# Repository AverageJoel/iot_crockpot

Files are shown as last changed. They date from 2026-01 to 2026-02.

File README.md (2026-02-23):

# IoT Crockpot Controller

An open-source, internet-enabled crockpot controller with a local touchscreen UI and remote Telegram control. Built on a custom single-board design around the ESP32-S3-WROOM-1-N4R2 and a 3.5" IPS capacitive touch display.

## Features

- **Remote Control via Telegram** — Control and monitor from anywhere; automatic safety alerts sent to Telegram on shutoff events
- **3.5" IPS Capacitive Touchscreen** — Full-color LVGL UI with OFF/WARM/LOW/HIGH controls, temperature arc, and multi-screen navigation
- **K-Type Thermocouple** — Accurate temperature monitoring via MAX31855
- **Safety System** — Auto-shutoff at 300°F, persistent sensor-error shutoff, task watchdog timer, relay fails to OFF on any fault
- **NVS Configuration** — WiFi credentials and Telegram token stored in non-volatile flash; configurable via `idf.py menuconfig`

## Architecture

Single custom PCB — ESP32-S3 handles everything directly:

```
                    ┌───────────────────────────────────────┐
                    │        ESP32-S3-WROOM-1-N4R2          │
                    │                                       │
   USB-C ──────────►│ GPIO19/20 (USB Serial/JTAG)           │
                    │                                       │
   3.5" Display ───►│ SPI2: SCK/MOSI/MISO + LCD_CS/DC/RST  │
   FT6336U Touch ──►│ I2C:  SDA/SCL + CTP_RST/INT          │
   Backlight PWM ───►│ GPIO47 (LCD_BL)                      │
                    │                                       │
   MAX31855 TC ─────►│ SPI2: MISO/SCK + TC_CS (GPIO16)      │
   Relay/SSR ───────►│ GPIO17                               │
                    │                                       │
                    │  WiFi 802.11n ──────────────► Internet│
                    └───────────────────────────────────────┘

Power: AC Mains → HLK-5M05 (5V) → AP2112K (3.3V) → ESP32 + Display + TC
```

See [docs/hardware_decisions.md](docs/hardware_decisions.md) for the full design rationale and component selection.

## Project Structure

```
iot_crockpot/
├── firmware/
│   ├── main/
│   │   ├── main.c              # Entry point, boot log, task creation
│   │   ├── crockpot.c/.h       # Core state machine (OFF/WARM/LOW/HIGH)
│   │   ├── temperature.c/.h    # MAX31855 SPI driver, thermocouple reading
│   │   ├── relay.c/.h          # GPIO relay/SSR control
│   │   ├── wifi.c/.h           # WiFi connection management
│   │   ├── telegram.c/.h       # Telegram bot (long-poll, commands, alerts)
│   │   ├── nvs_config.c/.h     # NVS read/write helpers
│   │   ├── display.c/.h        # LVGL init, lvgl_port setup
│   │   ├── display_driver.c/.h # ST7796 SPI driver (esp_lcd)
│   │   ├── touch_driver.c/.h   # FT6336U I2C driver (esp_lcd_touch)
│   │   ├── spi_bus.c/.h        # Shared SPI2 bus init
│   │   ├── gui.c/.h            # LVGL screens and widgets
│   │   ├── Kconfig.projbuild   # GPIO and WiFi/Telegram config options
│   │   └── idf_component.yml   # LVGL + esp_lcd component dependencies
│   ├── CMakeLists.txt
│   └── sdkconfig.defaults      # Default config (fonts, watchdog, etc.)
├── hardware/                   # KiCad PCB design (in progress)
│   ├── *.kicad_sch
│   ├── *.kicad_pcb
│   └── production/
├── docs/                       # Design docs and guides
│   ├── firmware_architecture.md
│   ├── firmware_plan.md
│   ├── hardware_decisions.md
│   ├── telegram_setup.md
│   ├── wiring.md
│   └── assembly.md
└── simulator/                  # Python simulator (partial)
```

## Hardware

| Component | Part | Notes |
|---|---|---|
| MCU | ESP32-S3-WROOM-1-N4R2 | 4MB flash, 2MB PSRAM, LCSC C2913203 |
| Display | 3.5" IPS SPI, ST7796 controller | 480×320, 16.7M colors |
| Touch | FT6336U (on display module) | I2C, 2-point capacitive |
| Thermocouple | MAX31855 + K-type probe | SPI, ±2°C accuracy |
| Relay | Omron G5LE-1 (10A SPDT) | NO contact, fail-safe OFF |
| Power supply | HLK-5M05 | AC-DC, 5V 5W |
| 3.3V LDO | AP2112K-3.3TRG1 | 5V→3.3V for ESP32 and peripherals |
| Input protection | 0.5A slow-blow fuse + MOV | Per HLK-5M05 datasheet |

## Getting Started

### Prerequisites

- [ESP-IDF v5.2+](https://docs.espressif.com/projects/esp-idf/en/latest/esp32s3/get-started/)

### Build and Flash

```bash
cd firmware
idf.py set-target esp32s3
idf.py menuconfig        # Configure WiFi, Telegram token, GPIO pins
idf.py build
idf.py flash monitor
```

### Configuration (`idf.py menuconfig` → *IoT Crockpot*)

| Setting | Where | Default |
|---|---|---|
| WiFi SSID / Password | IoT Crockpot → WiFi | (blank) |
| Telegram bot token | IoT Crockpot → Telegram | (blank) |
| Allowed Telegram chat ID | IoT Crockpot → Telegram | (blank = any) |
| All GPIO pin assignments | IoT Crockpot → SPI Bus / Display / Touch / Relay | See table below |

Credentials are saved to NVS on first boot and persist across reflashes that don't erase NVS.

### Default GPIO Assignments

| Signal | GPIO | Notes |
|---|---|---|
| SPI SCK | 12 | Shared: display + MAX31855 |
| SPI MOSI | 11 | |
| SPI MISO | 13 | |
| LCD CS | 10 | ST7796 |
| LCD DC | 9 | |
| LCD RST | 8 | |
| LCD BL | 47 | PWM backlight |
| Touch SDA | 5 | FT6336U I2C |
| Touch SCL | 4 | |
| Touch RST | 6 | |
| Touch INT | 7 | |
| MAX31855 CS | 16 | Thermocouple |
| Relay | 17 | SSR/relay, active-high |
| USB D- | 19 | Fixed, native USB |
| USB D+ | 20 | Fixed, native USB |

## Telegram Commands

| Command | Description |
|---|---|
| `/status` | Current state, temperature, uptime, WiFi |
| `/off` | Turn off |
| `/warm` | Set to warm |
| `/low` | Set to low |
| `/high` | Set to high |
| `/help` | List commands |

Safety events (temperature limit, sensor error) automatically send an alert to the configured chat ID without requiring a command.

See [docs/telegram_setup.md](docs/telegram_setup.md) for bot creation and configuration steps.

## Safety

- Auto-shutoff above 300°F (configurable in source)
- Persistent sensor error shutoff (10 consecutive bad readings while heating)
- Relay wired normally-open — de-energizes to OFF on any fault, power loss, or firmware crash
- Task watchdog timer: control loop must tick every second or the chip resets
- Safety alerts sent via Telegram on any automatic shutoff

**WARNING:** This project involves mains voltage. Only attempt if you have relevant electrical experience. Always follow local electrical codes and safety practices.

## Development Status

### Firmware
- [x] Core state machine (OFF/WARM/LOW/HIGH, mutex-protected)
- [x] MAX31855 thermocouple SPI driver
- [x] Relay/SSR control (active-high/low configurable)
- [x] WiFi connection management (NVS credentials, retry logic)
- [x] Telegram bot (long-poll, commands, NVS token, chat ID whitelist)
- [x] Telegram safety alerts (non-blocking queue, fires on auto-shutoff)
- [x] NVS config helpers (shared wifi + telegram storage)
- [x] ST7796 SPI display driver (esp_lcd)
- [x] FT6336U I2C touch driver (esp_lcd_touch)
- [x] LVGL integration (esp_lvgl_port)
- [x] Full touchscreen UI (4 screens, arc indicator, status bar, toast overlay)
- [x] Task watchdog timer (esp_task_wdt)
- [x] Boot log (chip info, IDF version, all GPIO pins)

### Hardware (PCB)
- [x] Architecture finalized (single-board ESP32-S3, ST7796 SPI display)
- [x] AC supply section (fuse, MOV, HLK-5M05)
- [x] Relay section (G5LE-1, 2N7002 driver, flyback diode)
- [ ] ESP32-S3 MCU section (in progress)
- [ ] USB-C connector
- [ ] AP2112K-3.3 LDO
- [ ] Display header (14-pin)
- [ ] MAX31855 thermocouple
- [ ] PCB layout
- [ ] Gerber generation
- [ ] Prototype build and validation

## Documentation

| Document | Description |
|---|---|
| [firmware_architecture.md](docs/firmware_architecture.md) | Firmware module breakdown, task structure, LVGL stack |
| [hardware_decisions.md](docs/hardware_decisions.md) | Component selection rationale, ESP32-S3 vs alternatives |
| [schematic_rework_plan.md](docs/schematic_rework_plan.md) | Step-by-step KiCad schematic rework guide |
| [telegram_setup.md](docs/telegram_setup.md) | Bot creation and configuration guide |
| [wiring.md](docs/wiring.md) | Bench wiring guide |
| [assembly.md](docs/assembly.md) | Assembly instructions |

## License

This project is open source. License TBD.

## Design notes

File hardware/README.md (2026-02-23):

# IoT Crockpot Power Board

Custom PCB for the IoT Crockpot controller. Single-board design — the ESP32-S3
handles WiFi, display, thermocouple, relay, and USB directly with no secondary MCU.

## Architecture

```
AC Mains ──► Fuse ──► MOV ──► HLK-5M05 ──► P-FET ──► 5V Rail
                                           (AO3401)      │
                                         Gate: 100K→GND  │
                                         G-S: 100nF cap  │
                                                         │
                              ┌──────────────────────────┘
                              │
                              ├──► AP2112K-3.3 LDO ──► 3.3V Rail
                              │                           │
                              │              ┌────────────┘
                              │              │
                              │         ESP32-S3-WROOM-1-N4R2
                              │              │
                              │              ├──► ST7796 Display (SPI)
                              │              ├──► FT6336U Touch (I2C)
                              │              ├──► MAX31855 TC (SPI)
                              │              ├──► Relay driver (GPIO → 2N7002)
                              │              └──► USB-C (GPIO19/20, native)
                              │
                              └──► Relay coil supply (5V)

AC Mains ──► Relay NO contact ──► Crockpot heating element
```

## Project Files

- `iot_crockpot.kicad_pro` — KiCad project file
- `iot_crockpot.kicad_sch` — Top-level schematic (hierarchical sheets)
- `MCU.kicad_sch` — ESP32-S3 MCU sheet
- `power_relays_tempsens.kicad_sch` — Power supply, relay, thermocouple sheet
- `iot_crockpot.kicad_pcb` — PCB layout

## Schematic Status

| Section | Status |
|---|---|
| AC input (fuse, MOV, HLK-5M05) | Done |
| 5V backfeed protection (P-FET AO3401) | Pending |
| AP2112K-3.3 LDO | Pending |
| ESP32-S3-WROOM-1-N4R2 | In progress |
| USB-C connector (GCT USB4085 / HRO TYPE-C-31-M-12) | Pending |
| 14-pin display header (ST7796 + FT6336U) | Pending |
| MAX31855 thermocouple | Pending |
| Relay driver (2N7002 MOSFET) | Done |
| Relay (G5LE-1) | Done |
| Connectors (AC screw terminals, thermocouple) | Done |

See [docs/schematic_rework_plan.md](../docs/schematic_rework_plan.md) for the
step-by-step schematic rework guide.

## Components

### MCU
| Part | Value | Package | LCSC # |
|---|---|---|---|
| ESP32-S3-WROOM-1-N4R2 | 4MB flash, 2MB PSRAM | Module | C2913203 |

### Display Interface
| Part | Value | Notes |
|---|---|---|
| J_DISPLAY | 14-pin 2.54mm header | ST7796 SPI display + FT6336U touch |

Display modules (all electrically equivalent, 14-pin 2.54mm interface):
- Hosyond (Amazon B0CMD7Y55M) ~$15
- Waveshare 3.5" Capacitive Touch LCD ~$19
- Elecrow 3.5" IPS SPI LCD ~$17

**Note:** Use ST7796 controller only. Avoid ILI9488 — no 16-bit SPI color and
broken MISO tristate cause SPI bus conflicts.

### 3.3V LDO
| Part | Value | Package | LCSC # |
|---|---|---|---|
| AP2112K-3.3TRG1 | 3.3V 600mA | SOT-23-5 | (search) |

### Power Supply
| Part | Value | Notes |
|---|---|---|
| HLK-5M05 | 5V 5W | AC-DC isolated PSU module |

### USB
| Part | Value | LCSC # | Notes |
|---|---|---|---|
| USB-C receptacle | GCT USB4085 or HRO TYPE-C-31-M-12 | C2765186 / C165948 | USB 2.0 only |
| R_D- | 22Ω 0402 | — | GPIO19 to D- |
| R_D+ | 22Ω 0402 | — | GPIO20 to D+ |
| R_CC1 | 5.1K 0402 | — | CC1 to GND |
| R_CC2 | 5.1K 0402 | — | CC2 to GND |

### AC Input Protection
| Part | Value | LCSC # | Notes |
|---|---|---|---|
| Fuse holder | 5x20mm clips | C3130 | Xucheng pair |
| Fuse | 0.5A 250V slow-blow | C142839 | Littelfuse 0215.500MXP |
| MOV | 10D561K | (search) | Per HLK datasheet |

### Temperature Sensing
| Part | Value | Notes |
|---|---|---|
| MAX31855KASA | K-type interface | SPI, cold junction compensated |
| Thermocouple | K-type probe | High temp |

### Relay
| Part | Value | Notes |
|---|---|---|
| Omron G5LE-1 | SPDT 10A | 5V coil |
| 2N7002 | N-ch MOSFET | Relay driver (x2) |
| 1N4148WQ-13-F | Flyback diode | SOD-123 |
| 10K resistor | Gate pull-down | Keeps relay off when GPIO floating |

### Protection
| Part | Value | Notes |
|---|---|---|
| P-FET (AO3401) | SOT-23 | Blocks USB-C VBUS backfeed into HLK-5M05 |
| 100K resistor | Gate to GND | P-FET gate bias |
| 100nF cap | Gate-source | Miller coupling suppression |

### Connectors
| Part | Value | LCSC # | Notes |
|---|---|---|---|
| Screw terminal (x2) | Phoenix 1935161 | (search) | AC mains in, relay out |

## GPIO Assignments

| Signal | GPIO | Notes |
|---|---|---|
| SPI SCK | 12 | Shared: display, MAX31855 |
| SPI MOSI | 11 | |
| SPI MISO | 13 | |
| LCD CS | 10 | |
| LCD DC | 9 | |
| LCD RST | 8 | |
| LCD BL | 47 | PWM backlight |
| SD CS | 14 | SD card on display module |
| Touch SDA | 5 | I2C |
| Touch SCL | 4 | I2C |
| Touch RST | 6 | |
| Touch INT | 7 | |
| MAX31855 CS | 16 | |
| Relay | 17 | Via 2N7002 driver |
| USB D- | 19 | Fixed, native USB |
| USB D+ | 20 | Fixed, native USB |

## ESP32-S3 Strapping Pins

| Pin | Default | Action |
|-----|---|---|
| GPIO0 | Pull-up to 3V3 | Ensures SPI Boot (normal) on power-up |
| GPIO46 | Float (internal pull-down) | Leave unconnected |
| EN | 10K to 3V3 + 1µF to GND | RC filter for clean power-on reset |

BOOT jumper: 2-pin 2.54mm header (GPIO0 to GND). Install to enter download mode on
next reset. Remove for normal boot. Not needed for routine flashing — native USB
handles auto-reset via esptool.py.

## Safety Notes

- **Mains Isolation**: HLK-5M05 provides isolation; maintain clearance on PCB
- **Creepage/Clearance**: Follow IPC-2221 for mains voltage traces
- **Fuse**: Must be rated for AC mains (250VAC)
- **Relay Wiring**: Use NO contact for fail-safe (de-energized = OFF)

## Fabrication Notes

1. Generate Gerbers to `production/gerbers/`
2. 2-layer board, 1.6mm thickness
3. HASL or ENIG finish
4. Minimum 2oz copper for mains traces

## References

- [Hardware Decisions](../docs/hardware_decisions.md) — Component selection rationale
- [Schematic Rework Plan](../docs/schematic_rework_plan.md) — Step-by-step rework guide
- [ESP32-S3 Hardware Design Guidelines](https://docs.espressif.com/projects/esp-hardware-design-guidelines/en/latest/esp32s3/schematic-checklist.html)
- [ST7796 Display Module](https://www.lcdwiki.com/3.5inch_IPS_SPI_Module_ST7796)
- [Omron G5LE-1 Datasheet](http://www.omron.com/ecb/products/pdf/en-g5le.pdf)

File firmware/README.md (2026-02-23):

# IoT Crockpot Firmware

ESP-IDF firmware for the IoT Crockpot controller, targeting the custom single-board
ESP32-S3 PCB.

## Hardware Target

- **MCU**: ESP32-S3-WROOM-1-N4R2 (4MB flash, 2MB PSRAM)
- **Display**: 3.5" IPS SPI, ST7796 controller (480×320, capacitive touch)
- **Touch**: FT6336U I2C (on display module)
- **Temperature Sensor**: MAX31855 + K-type thermocouple (SPI)
- **Relay**: Omron G5LE-1 via 2N7002 MOSFET driver
- **USB**: Native USB Serial/JTAG (GPIO19/20, no bridge chip)

## Current Status

| Module | Status | Notes |
|---|---|---|
| Core state machine | Done | OFF/WARM/LOW/HIGH, mutex-protected |
| MAX31855 thermocouple | Done | SPI driver, fault detection |
| Relay control | Done | Active-high/low configurable |
| WiFi | Done | NVS credentials, retry logic |
| Telegram bot | Done | Long-poll, commands, NVS token, chat ID whitelist |
| Telegram safety alerts | Done | Non-blocking queue, fires on auto-shutoff |
| NVS config | Done | Shared WiFi + Telegram storage |
| ST7796 display driver | Done | esp_lcd SPI driver |
| FT6336U touch driver | Done | esp_lcd_touch I2C driver |
| LVGL integration | Done | esp_lvgl_port |
| Touchscreen UI | Done | 4 screens, arc indicator, status bar, toast overlay |
| Task watchdog | Done | Control loop must tick every second |
| Boot log | Done | Chip info, IDF version, all GPIO pins |

## GPIO Assignments

| Signal | GPIO | Notes |
|---|---|---|
| SPI SCK | 12 | Shared: display + MAX31855 |
| SPI MOSI | 11 | |
| SPI MISO | 13 | |
| LCD CS | 10 | ST7796 |
| LCD DC | 9 | |
| LCD RST | 8 | |
| LCD BL | 47 | PWM backlight |
| Touch SDA | 5 | FT6336U I2C |
| Touch SCL | 4 | |
| Touch RST | 6 | |
| Touch INT | 7 | |
| MAX31855 CS | 16 | Thermocouple |
| Relay | 17 | SSR/relay, active-high |
| USB D- | 19 | Fixed, native USB Serial/JTAG |
| USB D+ | 20 | Fixed, native USB Serial/JTAG |

All GPIO assignments are configurable via `idf.py menuconfig` → *IoT Crockpot*.

## Building

### Prerequisites

- [ESP-IDF v5.2+](https://docs.espressif.com/projects/esp-idf/en/latest/esp32s3/get-started/)

### Build Commands

```bash
cd firmware

# Set target (one-time)
idf.py set-target esp32s3

# Configure GPIO pins, WiFi credentials, Telegram token
idf.py menuconfig

# Build
idf.py build

# Flash and monitor (native USB — no CH340 needed)
idf.py flash monitor
```

### Configuration (`idf.py menuconfig` → *IoT Crockpot*)

| Setting | Default |
|---|---|
| WiFi SSID / Password | (blank) |
| Telegram bot token | (blank) |
| Allowed Telegram chat ID | (blank = any) |
| All GPIO pin assignments | See table above |

Credentials are saved to NVS on first boot and persist across reflashes that don't erase NVS.

## Project Structure

```
firmware/
├── main/
│   ├── main.c              # Entry point, boot log, task creation
│   ├── crockpot.c/.h       # Core state machine (OFF/WARM/LOW/HIGH)
│   ├── temperature.c/.h    # MAX31855 SPI driver, thermocouple reading
│   ├── relay.c/.h          # GPIO relay/SSR control
│   ├── wifi.c/.h           # WiFi connection management
│   ├── telegram.c/.h       # Telegram bot (long-poll, commands, alerts)
│   ├── nvs_config.c/.h     # NVS read/write helpers
│   ├── display.c/.h        # LVGL init, lvgl_port setup
│   ├── display_driver.c/.h # ST7796 SPI driver (esp_lcd)
│   ├── touch_driver.c/.h   # FT6336U I2C driver (esp_lcd_touch)
│   ├── spi_bus.c/.h        # Shared SPI2 bus init
│   ├── gui.c/.h            # LVGL screens and widgets
│   ├── Kconfig.projbuild   # GPIO and WiFi/Telegram config options
│   └── idf_component.yml   # LVGL + esp_lcd component dependencies
├── CMakeLists.txt
└── sdkconfig.defaults      # Default config (fonts, watchdog, etc.)
```

## Telegram Commands

| Command | Description |
|---|---|
| `/status` | Current state, temperature, uptime, WiFi |
| `/off` | Turn off |
| `/warm` | Set to warm |
| `/low` | Set to low |
| `/high` | Set to high |
| `/help` | List commands |

Safety events (temperature limit, sensor error) automatically send an alert to the
configured chat ID.

See [docs/telegram_setup.md](../docs/telegram_setup.md) for bot creation steps.

## Safety Features

- Auto-shutoff above 300°F (configurable in source)
- Persistent sensor error shutoff (10 consecutive bad readings while heating)
- Relay wired normally-open — de-energizes to OFF on any fault or power loss
- Task watchdog timer: control loop must tick every second or chip resets
- Safety alerts sent via Telegram on any automatic shutoff

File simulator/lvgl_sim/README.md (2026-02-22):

# LVGL PC Simulator

Runs the actual `gui.c` firmware code on the desktop in a 960×640 SDL2 window
(2× scaled from the physical 480×320 display). Mouse acts as touch input.

## What This Is

This is **not** a re-implementation of the UI. It compiles and links the real
`firmware/main/gui.c` directly, with thin stubs replacing ESP-IDF headers and
mock implementations of hardware-dependent modules.

The result is pixel-accurate LVGL rendering with full touch interaction, a
live HTTP control API, simulated thermal physics, and Telegram bot support —
no flash cycle required to iterate on the UI.

## Prerequisites

- CMake 3.20+
- A C compiler:
  - **Windows**: MSYS2/MinGW (`pacman -S mingw-w64-ucrt-x86_64-gcc mingw-w64-ucrt-x86_64-cmake`)
  - **Linux**: `apt install gcc cmake`
  - **macOS**: Xcode CLT + `brew install cmake`
- SDL2 (optional — fetched automatically if not found):
  - Windows/MSYS2: `pacman -S mingw-w64-ucrt-x86_64-SDL2`
  - Linux: `apt install libsdl2-dev`
  - macOS: `brew install sdl2`
- Internet connection on first build (fetches LVGL v9.2.2 and mongoose v7.14)

## Build

**Windows (MSYS2 UCRT64 shell):**
```bash
cd simulator/lvgl_sim
mkdir build && cd build
cmake .. -G Ninja -DCMAKE_C_COMPILER=/c/msys64/ucrt64/bin/gcc.exe
cmake --build .
```

**Linux / macOS:**
```bash
cd simulator/lvgl_sim
mkdir build && cd build
cmake ..
cmake --build . --parallel
```

First build downloads LVGL v9.2.2 and mongoose v7.14 via git, and optionally
SDL2. Subsequent builds are incremental and fast.

> **Windows note**: Run from the MSYS2 UCRT64 shell (not Git Bash or CMD) so
> that cmake, ninja, and gcc are on `PATH`. Install prerequisites with:
> `pacman -S mingw-w64-ucrt-x86_64-gcc mingw-w64-ucrt-x86_64-cmake mingw-w64-ucrt-x86_64-ninja mingw-w64-ucrt-x86_64-SDL2`

## Run

**Windows — launch from the MSYS2 UCRT64 shell:**
```bash
cd /c/Users/Joel/Documents/Hardware_Projects/iot_crockpot/simulator/lvgl_sim/build
./crockpot_sim.exe
```

**Linux / macOS:**
```bash
cd simulator/lvgl_sim/build
./crockpot_sim
```

A 960×640 window opens showing the main crockpot screen. Expected terminal output:
```
[web_server] listening on http://localhost:8080
[telegram] SIM_TELEGRAM_TOKEN not set — Telegram disabled
IoT Crockpot Simulator running at 960x640 (LVGL 480x320 × 2)
```

> **Why the MSYS2 shell on Windows?** The executable is built with MSYS2's GCC
> and links against MSYS2 runtime DLLs (`libgcc_s_seh-1.dll`,
> `libwinpthread-1.dll`, etc.) that live in `C:\msys64\ucrt64\bin\`. Running
> from the MSYS2 UCRT64 shell puts that directory on `PATH` automatically so
> the DLLs are found. Double-clicking the `.exe` from Explorer will fail with a
> missing DLL error unless those DLLs are copied next to the executable or
> added to the system `PATH`.

Once running:
- The GUI window responds to mouse clicks (touch input) and keyboard shortcuts
- The web control page is at **http://localhost:8080/**
- The JSON API is at **http://localhost:8080/api/status**

## How It Works on Windows

The simulator is a **native Windows `.exe`** — not emulation, not WSL. Each
component is a cross-platform C library compiled by GCC for x86-64 Windows:

| Component | Role | Windows implementation |
|---|---|---|
| **SDL2** | Window creation + mouse/keyboard input | Calls `CreateWindow` / Win32 APIs |
| **LVGL** | UI rendering | Pure C — writes pixels into a buffer, no OS calls |
| **mongoose** | HTTP server | Uses Winsock2 (`ws2_32.dll`) instead of BSD sockets |
| **GCC (MSYS2)** | Compiler | Produces native PE executables |
| **`gui.c`** | UI logic | Plain C, calls only LVGL and `crockpot_*` — compiles anywhere |

At runtime the data flow is:

```
LVGL renders widgets → pixel buffer (RGB565)
    ↓
flush_cb() uploads dirty rectangles → SDL2 texture
    ↓
SDL2 scales 480×320 → 960×640 and presents to the window
    ↓  (every ~5 ms)
Mouse position → LVGL touch input
Keyboard events → crockpot state changes
mongoose polls for HTTP requests on :8080
1-second timer → crockpot_tick_s() (physics + schedule advance)
```

`gui.c` is completely unaware it is running on a PC. It calls
`crockpot_get_status()` and LVGL widget APIs exactly as it would on the
ESP32 — the stub implementations in `stubs/` provide the hardware behaviour.

## Keyboard Controls

| Key | Action |
|-----|---|
| `O` | Crockpot → OFF |
| `W` | Crockpot → WARM |
| `L` | Crockpot → LOW |
| `H` | Crockpot → HIGH |
| `1` | Start Slow Cook schedule (HIGH 1h → LOW 6h → WARM) |
| `2` | Start Quick Warm schedule (HIGH 30m → WARM) |
| `3` | Start All Day schedule (LOW 8h → WARM) |
| `↑` / `↓` | Temperature +/− 5°F |
| `E` | Toggle sensor error |
| `D` | Toggle WiFi connected |
| `X` | Export temperature log to CSV |
| `S` | Print current status to terminal |
| `T` | Show a test toast message |
| `R` | Show a test error overlay |
| `Q` / `Esc` | Quit |

Mouse clicks drive touch input — all buttons and screen navigation work.

## Web API

The simulator exposes an HTTP API on port 8080 (override with `SIM_HTTP_PORT`
environment variable). Open `http://localhost:8080/` for a browser control page.

| Method | Endpoint | Description |
|---|---|---|
| `GET`  | `/api/status` | Full JSON state snapshot |
| `POST` | `/api/state/{off\|warm\|low\|high}` | Set heat level |
| `GET`  | `/api/schedules` | List preset schedules |
| `POST` | `/api/schedule/start/{name}` | Start a named schedule (URL-encode spaces: `Slow%20Cook`) |
| `POST` | `/api/schedule/stop` | Stop active schedule |
| `GET`  | `/api/history` | Last 60 logged data points |

**Note:** POST requests require a `Content-Length` header. When using curl, add
`--data ''` to include one automatically. The browser control page handles this
correctly.

Example:
```bash
curl http://localhost:8080/api/status
curl -X POST http://localhost:8080/api/state/high --data ''
curl -X POST "http://localhost:8080/api/schedule/start/Slow%20Cook" --data ''
curl -X POST http://localhost:8080/api/schedule/stop --data ''
```

Status JSON example:
```json
{
  "state": "HIGH",
  "temperature_f": 245.3,
  "relay_main": true,
  "relay_aux": true,
  "sensor_error": false,
  "wifi_connected": true,
  "uptime_seconds": 3600,
  "uptime": "01:00:00",
  "schedule_active": true,
  "schedule_name": "Slow Cook",
  "schedule_step": 0,
  "schedule_total_steps": 3,
  "schedule_step_remaining_s": 3540,
  "schedule_step_progress": 0.02
}
```

## Telegram Bot (optional)

> **Status**: TLS/OpenSSL is enabled in the build and the bot connects, but
> command responses are not working yet. This is a known issue to be
> investigated. The setup steps below are complete — Telegram just needs
> debugging.

**Prerequisites — OpenSSL must be installed (MSYS2):**
```bash
pacman -S mingw-w64-ucrt-x86_64-openssl
```

**Create a bot** via `@BotFather` on Telegram if you don't have one:
1. Open Telegram and search for `@BotFather` (blue checkmark)
2. Send `/newbot`
3. Give it a name (e.g. `Crockpot`) and a username ending in `bot` (e.g. `mycrockpot_bot`)
4. Copy the token it gives you (looks like `123456789:ABCdef...`)

**Launch with the token** (PowerShell):
```powershell
$env:SIM_TELEGRAM_TOKEN="123456789:ABCdef..."
.\crockpot_sim.exe
```

You should see `[telegram] enabled (token: 12345678...)` in the terminal.

> **Security note**: Never put your bot token in code or commit it to git.
> Always pass it via environment variable. If it leaks, revoke it via
> BotFather (`/revoke`).

When enabled, supported commands:

| Command | Action |
|---|---|
| `/status` | Current state, temp, relay, uptime, schedule |
| `/off` `/warm` `/low` `/high` | Set heat level |
| `/schedule` | List available schedules |
| `/slow` `/quick` `/allday` | Start a preset schedule |
| `/stopschedule` | Stop active schedule |
| `/log` | Export CSV and report filename |
| `/help` | Command list |

## Data Logging

Temperature, state, and relay status are logged to an in-memory ring buffer
(1440 samples = 24 hours at 60-second intervals). Press `X` or send `/log` via
Telegram to export a timestamped CSV file to the current directory.

## Architecture

```
simulator/lvgl_sim/
├── CMakeLists.txt          Build: LVGL + SDL2 + mongoose (FetchContent) + gui.c + stubs
├── lv_conf.h               LVGL config: RGB565, chart widget, Montserrat fonts
├── main.c                  SDL2 init, LVGL init, event loop, keyboard handler,
│                           1s physics timer, 2s Telegram poll timer
└── stubs/
    ├── crockpot.c          Thermal physics simulation + schedule engine + relay logic
    ├── datalog.c/.h        1440-entry ring buffer, 60s sample interval, CSV export
    ├── web_server.c/.h     mongoose HTTP server on :8080, REST API handlers
    ├── telegram.c/.h       Telegram bot: getUpdates polling + sendMessage
    ├── display_driver.c/.h Backlight stub (logs to stderr / window title)
    ├── esp_log.h           ESP_LOGI/LOGE/LOGW → fprintf(stderr)
    ├── esp_lvgl_port.h     lvgl_port_lock/unlock → no-ops (single-threaded)
    ├── esp_timer.c/.h      esp_timer_get_time() → SDL_GetTicks() * 1000
    ├── freertos/FreeRTOS.h Empty stub (gui.c includes it but doesn't use it)
    ├── sim_controls.h      sim_crockpot_* and sim_wifi_* control declarations
    └── wifi.c/.h           Mock WiFi with toggleable connected state
```

The real `firmware/main/gui.c` and `firmware/main/gui.h` are compiled directly
(referenced by path in CMakeLists.txt — no copying needed).

### Thermal Physics (simulator only)

The `crockpot.c` stub simulates realistic temperature behaviour:

- **Heating**: linear ramp toward target, capped at +2°F/tick
- **Cooling**: exponential decay toward ambient (70°F when OFF, target temp otherwise)
- **Noise**: ±0.3°F random jitter per tick

Target temperatures: OFF→70°F, WARM→145°F, LOW→185°F, HIGH→265°F

**Relay mapping:**

| State | relay_main | relay_aux |
|---|---|---|
| OFF | OFF | OFF |
| WARM  | OFF | ON  |
| LOW | ON  | OFF |
| HIGH  | ON  | ON  |

**Safety shutoff**: automatically engages at >300°F, cancels any active schedule.

### Schedule Engine

Schedules are defined as ordered steps, each with a heat state and duration:

```
Slow Cook:   HIGH (1h) → LOW (6h) → WARM (∞)
Quick Warm:  HIGH (30m) → WARM (∞)
All Day:     LOW (8h) → WARM (∞)
```

`crockpot_tick_s()` is called every second from an LVGL timer. It counts down
the current step, advances to the next step when elapsed, and calls
`crockpot_set_state()` automatically.

## Troubleshooting

**Colors look wrong (inverted or swapped)**
Try adding `#define LV_COLOR_16_SWAP 1` to `lv_conf.h` and rebuilding.

**Window is blank after launch**
LVGL may not have rendered the first frame yet. Try clicking in the window to
trigger an indev read, which forces a redraw.

**Build error: `lv_conf.h` not found**
Ensure you are building from inside `simulator/lvgl_sim/build/`. The simulator
root is added to the include path by CMakeLists.txt.

**SDL2 download fails (corporate proxy / no internet)**
Install SDL2 via your system package manager, then re-run cmake — `find_package`
will pick it up and skip the FetchContent download.

**Port 8080 already in use**
Either a previous simulator instance is still running, or another service owns
the port. Kill the old process or set `SIM_HTTP_PORT=8081` before launching.

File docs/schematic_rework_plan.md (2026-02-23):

# Schematic Rework Plan: Two-Board → Single-Board ESP32-S3

Goal: Adapt the existing KiCad schematic (designed for CYD + STM32 two-board system) to the new
single-board ESP32-S3-WROOM-1-N4R2 design.

The AC power supply section is fully reusable. The MCU and inter-board interface sections need
to be replaced.

---

## Overview of Changes

| Action | What |
|---|---|
| **Keep** | Fuse + MOV + HLK-5M05 AC supply |
| **Keep** | AP2112K-3.3 LDO (still needed — ESP32-S3 module takes 3.3V, no internal 5V reg) |
| **Keep** | Omron G5LE-1 relay + 1N4148 flyback diode |
| **Keep** | Screw terminals (AC mains in, relay out) |
| **Keep** | Backfeed P-FET (now protects HLK from USB-C VBUS instead of from CYD P1) |
| **Remove** | STM32G031F6P6 and all its passives |
| **Remove** | 1K UART series resistors (R_TX, R_RX) |
| **Remove** | JST GH SM04B P1 4-pin connector (CYD cable) |
| **Add** | ESP32-S3-WROOM-1-N4R2 module |
| **Add** | USB-C connector + 22Ω D+/D- resistors + 5.1K CC pull-downs |
| **Add** | BOOT button + EN/Reset button |
| **Add** | 14-pin display header (ST7796 + FT6336U) |
| **Add** | Relay driver circuit (NPN transistor replaces STM32 direct drive) |
| **Modify** | MAX31855 SPI CS now goes to ESP32-S3 GPIO |

---

## Step 1: Remove STM32 Section

Delete from schematic:
- STM32G031F6P6 symbol
- All decoupling caps on STM32 VDD pins
- NRST RC filter (100nF cap + any pull-up)
- BOOT0 pull-down resistor and optional button
- SWD header (if present)
- UART series resistors R_TX (1K, PA9 → P1) and R_RX (1K, PA10 ← P1)
- JST GH SM04B 4-pin header (P1) for CYD cable

After removal, the MAX31855 SPI lines (CS, SCK, MISO) will be dangling — leave them
temporarily, they get reconnected in Step 5.

---

## Step 2: Verify / Update Power Supply Section

### Keep as-is:
- Fuse holder + 0.5A slow-blow fuse (C3130, C142839)
- MOV 10D561K across AC input
- HLK-5M05 AC-DC module

### Backfeed protection (P-FET) — keep but update net labels:
The P-FET (AO3401) is still needed. In the old design it blocked USB 5V from backfeeding
through P1 VIN into the HLK-5M05. In the new design it does the same job, now blocking
USB-C VBUS from backfeeding into HLK-5M05 via the shared 5V rail.

Circuit is identical:
```
HLK-5M05 Out → P-FET Source
P-FET Drain  → 5V Rail (to LDO, display, relay coil)
P-FET Gate   → 100K to GND (turns FET on when HLK powered)
Gate-Source  → 100nF cap (Miller coupling suppression)
```

If the P-FET circuit was pending/not yet drawn, add it now between the HLK output and
the 5V power rail net.

### AP2112K-3.3 LDO — keep:
- Input: 5V rail
- Output: 3V3 rail
- Decoupling: 1uF ceramic on input, 1uF ceramic on output
- This powers ESP32-S3 module (3.3V) + MAX31855 (3.3V)

Note: The ST7796 display module takes 5V input directly (it has onboard level shifters),
so it comes off the 5V rail, not the 3V3 rail.

---

## Step 3: Add ESP32-S3-WROOM-1-N4R2

### Symbol
- KiCad built-in: `RF_Module:ESP32-S3-WROOM-1` (check Espressif KiCad library)
- If not available: create from module datasheet or use a generic 38-pin header

### Power connections
- All VDD / 3V3 pins → 3V3 power net
- All GND pins → GND
- EN pin → 10K pull-up to 3V3 + 100nF cap to GND (RC filter) + EN button to GND

### Decoupling
- 100nF ceramic cap on each VDD pin (place near pin)
- 10uF bulk cap on 3V3 rail (one instance is fine)

### GPIO pin assignments (see table below)

### Boot/Reset buttons
```
BOOT button:  GPIO0 → button → GND
              GPIO0 → 10K pullup → 3V3

EN button:    EN pin → button → GND
              EN pin → 10K pullup → 3V3 (already handled by RC above)
              100nF cap EN to GND
```

### Strapping pin notes
| Pin | Concern | Action |
|-----|---|---|
| GPIO0 | Low on boot → download mode | BOOT button pulls low; float = high (normal boot) |
| GPIO45 | Sets VDD_SPI (3.3V vs 1.8V flash) | Leave floating or pull to GND (3.3V flash) |
| GPIO46 | ROM log enable | Leave floating |
| GPIO19 | USB D- | See Step 4 |
| GPIO20 | USB D+ | See Step 4 |

---

## Step 4: Add USB-C Connector

### Purpose
Native USB Serial/JTAG on ESP32-S3 — no CH340 or CP2102 needed. Used for:
- Firmware flashing
- Serial monitor / printf debugging
- JTAG debugging

### Circuit
```
ESP32-S3                       USB-C Connector
GPIO19 (D-) ──[22Ω]──────────── D- (pin A7/B7)
GPIO20 (D+) ──[22Ω]──────────── D+ (pin A6/B6)

USB-C CC1 ──[5.1K]── GND      (identifies device to host: 5V/900mA)
USB-C CC2 ──[5.1K]── GND

USB-C VBUS ──────────────────── 5V rail
             (5V rail also fed by HLK-5M05 via P-FET — both sources share the rail)
```

### Symbol / Footprint
- Symbol: `Connector:USB_C_Receptacle_USB2.0` (KiCad built-in)
- Footprint: SMD USB-C receptacle (search KiCad footprint library for USB_C)

---

## Step 5: Add Display Header (14-pin)

The ST7796 display module (lcdwiki MSP3526 / Waveshare / Hosyond) uses a standard
14-pin header. Wire to ESP32-S3 GPIOs per the table in Step 7.

### Header pinout
| Pin | Label | Function | ESP32-S3 GPIO |
|-----|---|---|---|
| 1 | VCC | 3.3V | 3V3 rail |
| 2 | GND | Ground | GND |
| 3 | LCD_CS | LCD chip select | GPIO10 |
| 4 | LCD_RST | LCD reset | GPIO8 |
| 5 | LCD_RS/DC | Command/data select | GPIO9 |
| 6 | SDI (MOSI) | SPI data in | GPIO11 |
| 7 | SCK | SPI clock | GPIO12 |
| 8 | LED | Backlight | GPIO47 |
| 9 | SDO (MISO) | SPI data out | GPIO13 |
| 10 | CTP_SCL | Touch I2C clock | GPIO4 |
| 11 | CTP_RST | Touch reset | GPIO6 |
| 12 | CTP_SDA | Touch I2C data | GPIO5 |
| 13 | CTP_INT | Touch interrupt | GPIO7 |
| 14 | SD_CS | SD card chip select | GPIO14 |

Note: LCD and SD card share the SPI bus (SCK/MOSI/MISO). Touch uses separate I2C bus.
Note: Display module VCC is 3.3V (module has level shifters for 5V logic, but ESP32-S3
is 3.3V — use 3.3V input, the level shifters pass through fine).

### Symbol / Footprint
- Symbol: `Connector:Conn_01x14_Pin` or create custom symbol with signal names
- Footprint: 2.54mm pitch 14-pin single-row header
  (`Connector_PinHeader_2.54mm:PinHeader_1x14_P2.54mm_Vertical`)

---

## Step 6: Update MAX31855 Thermocouple Section

If MAX31855 was already partially drawn, update the CS net label to connect to the
ESP32-S3 GPIO5.

### MAX31855 SPI connections
| Signal | ESP32-S3 GPIO | Notes |
|---|---|---|
| CS | GPIO5 | Active low |
| SCK | GPIO12 | Shared SPI bus |
| MISO | GPIO13 | Shared SPI bus |
| MOSI | N/A | MAX31855 is read-only |

### If not yet drawn, add:
- MAX31855KASA symbol (SPI thermocouple IC)
- VCC → 3V3, GND → GND
- 100nF decoupling cap on VCC
- K-type thermocouple connector (2-pin screw terminal or K-type jack)
- CS, SCK, MISO to ESP32-S3 GPIOs

---

## Step 7: Add Relay Driver Circuit

The STM32 previously drove the relay coil directly. The ESP32-S3 GPIO outputs 3.3V
and cannot drive a 5V relay coil directly. Add an NPN transistor driver.

### Circuit
```
ESP32-S3 GPIO4 ──[1K]── NPN Base
                         NPN Emitter → GND
                         NPN Collector → Relay Coil (-)
                                         Relay Coil (+) → 5V rail
                                         1N4148 flyback diode across coil (cathode to 5V)
```

### Component
- NPN transistor: 2N3904 (SOT-23, LCSC C20526) or 2N2222A
- Base resistor: 1K 0402/0603
- Flyback diode: 1N4148WQ-13-F (SOD-123, already in BOM)

Verification: Relay coil resistance = 56Ω, coil current = 5V/56Ω ≈ 89mA.
With 3.3V GPIO and 1K base resistor: Ib = (3.3-0.7)/1K = 2.6mA.
2N3904 hFE ≥ 100 → Ic_sat = 260mA >> 89mA. Transistor saturates fully. ✓

The existing relay (G5LE-1) and flyback diode symbol/footprint are unchanged.

---

## Step 8: GPIO Assignment Summary

| Signal | GPIO | Notes |
|---|---|---|
| SPI SCK | GPIO12 | Shared: LCD, SD, MAX31855 |
| SPI MOSI | GPIO11 | Shared: LCD, SD |
| SPI MISO | GPIO13 | Shared: LCD, SD, MAX31855 |
| LCD_CS | GPIO10 | |
| LCD_DC | GPIO9 | |
| LCD_RST | GPIO8 | |
| LCD_BL | GPIO47 | Backlight (PWM capable) |
| SD_CS | GPIO14 | SD card on display module |
| CTP_SDA | GPIO5 | I2C bus |
| CTP_SCL | GPIO4 | I2C bus |
| CTP_RST | GPIO6 | |
| CTP_INT | GPIO7 | |
| MAX31855_CS | GPIO16 | |
| Relay | GPIO17 | Via 2N7002 MOSFET driver |
| USB D- | GPIO19 | Fixed |
| USB D+ | GPIO20 | Fixed |
| BOOT | GPIO0 | Strapping / BOOT jumper |
| UART0_TX | GPIO43 | Debug serial (optional header) |
| UART0_RX | GPIO44 | Debug serial (optional header) |

Spare GPIOs (≥15 remaining): GPIO1, GPIO2, GPIO3, GPIO15, GPIO18, GPIO21,
GPIO35–GPIO42, GPIO45, GPIO46, GPIO48

---

## Step 9: Optional — Debug UART Header

Add a 3-pin header (TX, RX, GND) for UART0 debug output. Useful before USB firmware
is working. 2.54mm pitch.

- Pin 1: GPIO43 (UART0_TX)
- Pin 2: GPIO44 (UART0_RX)
- Pin 3: GND

---

## Step 10: ERC + Final Check

After all changes:

1. Run KiCad ERC (Electrical Rules Check) and resolve errors
2. Verify all power pins have power flags where needed
3. Check net labels are consistent (no orphan nets)
4. Verify P-FET circuit is between HLK output and 5V rail net
5. Confirm GPIO0 has both the 10K pullup and the BOOT button
6. Confirm EN has 10K pullup + 100nF + button

---

## New BOM Additions

| Component | Part | Package | LCSC # |
|---|---|---|---|
| ESP32-S3-WROOM-1-N4R2 | MCU module | — | C2913203 |
| USB-C receptacle | SMD USB-C | SMD | (search) |
| 22Ω resistor (x2) | USB D+/D- | 0402 | (search) |
| 5.1K resistor (x2) | USB CC1/CC2 | 0402 | (search) |
| 10K resistor (x3) | GPIO0 pullup, EN pullup, NPN base | 0402 | (search) |
| 1K resistor (x1) | NPN base resistor | 0402 | (search) |
| 100nF cap (x3) | EN filter, NPN gate, USB D± | 0402 | (search) |
| 10uF cap (x1) | 3V3 bulk | 0402/0603 | (search) |
| NPN transistor | 2N3904 | SOT-23 | C20526 |
| 14-pin header | Display connector | 2.54mm | (search) |
| 3-pin header | Debug UART | 2.54mm | (search) |

### Removed from BOM

| Component | Reason |
|---|---|
| STM32G031F6P6 | Replaced by ESP32-S3 |
| JST SM04B-GHS-TB 4-pin | CYD cable interface no longer needed |
| 1K resistors (UART protection) | No bus contention issue |
| STM32 passives (decoupling, NRST, BOOT0) | Removed with STM32 |

---

## References

- [ESP32-S3-WROOM-1 Datasheet](https://www.espressif.com/sites/default/files/documentation/esp32-s3-wroom-1_wroom-1u_datasheet_en.pdf)
- [ESP32-S3 Hardware Design Guidelines](https://docs.espressif.com/projects/esp-hardware-design-guidelines/en/latest/esp32s3/schematic-checklist.html)
- [ST7796 Display Module 14-pin interface](https://www.lcdwiki.com/3.5inch_IPS_SPI_Module_ST7796)
- [hardware_decisions.md](hardware_decisions.md) — full architecture rationale

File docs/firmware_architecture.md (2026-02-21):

# Firmware Architecture

ESP-IDF v5.x firmware for the IoT Crockpot. Target: ESP32-S3-WROOM-1-N4R2.

---

## Module Overview

```
main.c
  ├── wifi.c/.h           WiFi STA connection, NVS credentials
  ├── crockpot.c/.h       Core state machine, safety shutoff, alert callback
  │     ├── temperature.c/.h   MAX31855 SPI driver (via spi_bus)
  │     └── relay.c/.h         GPIO relay/SSR output
  ├── telegram.c/.h       Telegram bot long-poll, commands, alert queue
  ├── nvs_config.c/.h     Shared NVS read/write helpers
  └── display.c/.h        LVGL init and lvgl_port setup
        ├── spi_bus.c/.h        Shared SPI2 bus (display + MAX31855)
        ├── display_driver.c/.h ST7796 panel via esp_lcd
        ├── touch_driver.c/.h   FT6336U touch via esp_lcd_touch_ft5x06
        └── gui.c/.h            LVGL screens and widgets
```

Dependencies are one-directional. `crockpot.c` does not import `telegram.h` or `gui.h` — it exposes a callback that `main.c` connects to both.

---

## FreeRTOS Tasks

| Task | Function | Stack | Priority | Notes |
|---|---|---|---|---|
| `app_main` | `app_main()` | ESP-IDF default | 1 | Runs init sequence, then periodic 30s status log |
| `control` | `crockpot_control_task()` | 4 KB | 5 | 1 Hz loop; reads temperature, runs safety checks, feeds TWDT |
| `telegram` | `telegram_task()` | 8 KB | 3 | Long-polls Telegram API, processes commands, drains alert queue |
| `display` | `display_task()` | 4 KB | 4 | LVGL port internal task (started by `lvgl_port_init`) |

The LVGL task is managed internally by `esp_lvgl_port`. External tasks (e.g., the control task via the alert callback) must acquire the LVGL lock (`lvgl_port_lock` / `lvgl_port_unlock`) before calling any LVGL API.

---

## Display Stack

```
spi_bus.c
  └── spi_bus_init()
        Initializes SPI2_HOST with SCK/MOSI/MISO.
        Called once; shared by display driver and MAX31855.

display_driver.c
  └── display_driver_init()
        Creates esp_lcd_io_handle_t (SPI IO) for ST7796.
        Creates esp_lcd_panel_handle_t via esp_lcd_new_panel_st7796().
        Resets, inits, and turns on panel.
        Configures landscape rotation (480×320).
        Sets up PWM backlight on LCD_BL GPIO.

touch_driver.c
  └── touch_driver_init()
        Initializes I2C master bus on SDA/SCL.
        Creates esp_lcd_touch_handle_t via esp_lcd_touch_new_i2c_ft5x06().

display.c
  └── display_init()
        Calls spi_bus_init(), display_driver_init(), touch_driver_init().
        Calls lvgl_port_init() — starts LVGL internal task.
        Registers display flush callback (lvgl_port_add_disp).
        Registers touch read callback (lvgl_port_add_touch).
        Returns esp_lcd_panel_handle_t and esp_lcd_touch_handle_t
        via display_get_lvgl_disp() / display_get_lvgl_indev().

gui.c
  └── gui_init()
        Builds all LVGL screen objects (main, settings, WiFi, info).
        Starts a 500ms lv_timer for status updates.
  └── gui_start()
        Loads the main screen.
```

---

## GUI Screens

Layout: 480×320 landscape, dark theme (`#1a1a2e` background).

### Main Screen

```
┌─────────────────────────────────────────────────────┐
│                                                     │
│              ◉  LOW                                 │
│         (270° arc, color-coded by state)            │
│                                                     │
│              185.4 °F                               │
│                                                     │
│   ┌────────┐  ┌────────┐  ┌────────┐  ┌────────┐   │
│   │  OFF   │  │  WARM  │  │  LOW   │  │  HIGH  │   │
│   └────────┘  └────────┘  └────────┘  └────────┘   │
│                                                     │
│  WiFi ●      00:42:15              ⚙           ℹ   │
└─────────────────────────────────────────────────────┘
```

| State | Arc / button color |
|---|---|
| OFF | Gray `#555555` |
| WARM | Yellow `#ffaa00` |
| LOW | Orange `#ff6600` |
| HIGH | Red `#ff2200` |

- WiFi icon is tappable → navigates to WiFi screen
- Settings button → Settings screen
- Info button → Info screen
- Status updated every 500ms via `lv_timer`

### Settings Screen
- Celsius/Fahrenheit toggle

### WiFi Screen
- Connection state, SSID, IP address

### Info Screen
- Uptime (H:M:S), firmware version

### Toast Overlay
Displayed on `lv_layer_top()` so it floats over all screens.
- Blue background for normal messages (`gui_show_message`)
- Red background for errors (`gui_show_error`)
- Tap to dismiss; auto-dismisses after `duration_ms` for normal messages
- Error toasts persist until dismissed

---

## Core State Machine (`crockpot.c`)

States: `CROCKPOT_OFF`, `CROCKPOT_WARM`, `CROCKPOT_LOW`, `CROCKPOT_HIGH`

All state and status fields are protected by `s_state_mutex` (FreeRTOS mutex). `crockpot_get_status()` and `crockpot_set_state()` are both thread-safe.

### Control Loop (1 Hz)

Each iteration:
1. Read thermocouple (SPI, before taking mutex — ~1ms)
2. Acquire mutex
3. Update `s_status.temperature_f`, `.sensor_error`, `.uptime_seconds`, `.wifi_connected`
4. Safety check — temperature limit:
   - If `was_heating && temp > 300°F` → set state=OFF, `relay_all_off()`, set `temp_shutoff` flag
5. Safety check — sensor error:
   - If `was_heating && sensor_error` → increment `sensor_error_count`
   - If `sensor_error_count > 10` → set state=OFF, `relay_all_off()`, set `sensor_shutoff` flag, reset count
6. Release mutex
7. Fire alert callbacks outside mutex (safe to call `crockpot_get_status()` from handler)
8. Feed task watchdog (`esp_task_wdt_reset()`)
9. Wait until next 1s tick (`vTaskDelayUntil`)

### Safety Alert Callback

```c
// Register in main.c:
crockpot_set_alert_callback(on_safety_alert);

// Callback signature:
typedef void (*crockpot_alert_cb_t)(crockpot_alert_t reason, float temp_f);

// Reasons:
CROCKPOT_ALERT_TEMP_LIMIT    // temperature exceeded 300°F
CROCKPOT_ALERT_SENSOR_ERROR  // 10+ consecutive bad readings while heating
```

The callback fires only on the heating→OFF transition, not every loop iteration.
`main.c` wires it to both `telegram_queue_alert()` and `gui_show_error()`.

---

## Telegram Integration

### Long Polling

`telegram_task()` calls `getUpdates` with a 30-second timeout. After each response:
1. Parses JSON, processes any commands
2. Drains the alert queue (sends any pending safety alerts)
3. 100ms delay, then next poll

### Commands

Inbound commands (`/status`, `/off`, `/warm`, `/low`, `/high`, `/help`) are processed in `process_command()`. The chat ID whitelist (`CONFIG_CROCKPOT_TELEGRAM_ALLOWED_CHAT_ID`) is enforced on every incoming message; leave blank to allow any chat ID.

### Alert Queue

For outbound alerts from other tasks (e.g., safety shutoffs from the control task):

```c
// Non-blocking — safe from any FreeRTOS task:
telegram_queue_alert("SAFETY SHUTOFF: Temperature 305.2 F exceeded limit.");
```

- Queue depth: 4 messages × 128 bytes
- `xQueueSend` with zero timeout — drops silently if full
- Drained by `telegram_task()` after each getUpdates cycle
- Alert chat ID is the same as `CONFIG_CROCKPOT_TELEGRAM_ALLOWED_CHAT_ID`

### Token and Chat ID Storage

Priority at init: NVS → Kconfig default. `telegram_set_token()` writes to NVS for persistence.

---

## NVS Config (`nvs_config.c`)

Thin wrappers over `nvs_flash` for string read/write:

```c
nvs_config_read_str(NVS_NS_WIFI, NVS_KEY_WIFI_SSID, buf, len);
nvs_config_write_str(NVS_NS_TELEGRAM, NVS_KEY_TG_TOKEN, token);
```

Namespaces: `NVS_NS_WIFI` (`"wifi"`), `NVS_NS_TELEGRAM` (`"telegram"`).

---

## Task Watchdog

The control task registers with the ESP Task Watchdog Timer at startup:

```c
esp_task_wdt_add(NULL);   // register current task
// ... each loop iteration:
esp_task_wdt_reset();
```

TWDT is configured in `sdkconfig.defaults`:
```
CONFIG_ESP_TASK_WDT_EN=y
CONFIG_ESP_TASK_WDT_PANIC=y
CONFIG_ESP_TASK_WDT_TIMEOUT_S=10
```

If the control loop hangs for >10 seconds, the chip resets via panic handler.

---

## Build Configuration (`sdkconfig.defaults`)

Key non-default settings:

```
# Target
CONFIG_IDF_TARGET="esp32s3"

# PSRAM (OPI PSRAM on N4R2)
CONFIG_SPIRAM=y
CONFIG_SPIRAM_MODE_OCT=y

# LVGL fonts
CONFIG_LV_FONT_MONTSERRAT_14=y
CONFIG_LV_FONT_MONTSERRAT_16=y
CONFIG_LV_FONT_MONTSERRAT_20=y
CONFIG_LV_FONT_MONTSERRAT_28=y

# Task watchdog
CONFIG_ESP_TASK_WDT_EN=y
CONFIG_ESP_TASK_WDT_PANIC=y
CONFIG_ESP_TASK_WDT_TIMEOUT_S=10
```

GPIO defaults are set in `Kconfig.projbuild` (not `sdkconfig.defaults`) so they appear in `menuconfig`.

---

## Component Dependencies (`idf_component.yml`)

```yaml
dependencies:
  lvgl/lvgl: "^9.0.0"
  espressif/esp_lvgl_port: "^2.0.0"
  espressif/esp_lcd_st7796: "*"
  espressif/esp_lcd_touch_ft5x06: "*"
```

`esp_lcd` and `esp_lcd_touch` are part of ESP-IDF v5 and do not need separate component entries.

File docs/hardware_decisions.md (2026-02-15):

# Hardware Architecture Decisions

Notes from design discussion - February 2026

## Two-Board Architecture

### CYD Display Board (off-the-shelf)
- **Model**: ESP32-3248S035C (Cheap Yellow Display)
- **Display**: 3.5" 320x480 TFT ST7796, capacitive touch (GT911)
- **MCU**: ESP32-WROOM-32
- **Role**: WiFi, Telegram, touchscreen UI, UART master

### Power Board (custom PCB)
- **MCU**: STM32G031F6P6 (TSSOP-20)
- **Role**: UART to CYD, relay control, temperature sensing, local safety logic

## Why STM32G031?
- STM32G031 vs G030: G031 has **125°C temperature rating** (important near heating element)
- Cortex-M0+, ~$1, TSSOP-20 easy to hand solder
- Built-in UART bootloader for firmware updates via CYD (PA9/PA10)

## CYD Connector

### P1 (4-pin 1.25mm JST) - Power + UART
| Pin | Function |
|-----|---|
| VIN | 5V input from power board |
| TX | UART TX → STM32 PA10 (USART1_RX) |
| RX | UART RX ← STM32 PA9 (USART1_TX) |
| GND | Ground |

CN1 connector is **not used** — the power board has a local 3.3V LDO (AP2112K-3.3) instead of receiving 3.3V from the CYD.

Source: https://github.com/witnessmenow/ESP32-Cheap-Yellow-Display/blob/main/PINS.md

## STM32G031F6P6 TSSOP-20 Pinout

```
        ┌──────────┐
  PB7 ──┤1       20├── PB3/PB4/PB5/PB6 (bonded)
  PB8 ──┤2       19├── PA15
  PB9 ──┤3       18├── PA14 (SWCLK/BOOT0)
  VDD ──┤4       17├── PA13 (SWDIO)
  VSS ──┤5       16├── PA12
 NRST ──┤6       15├── PA11/PB0/PB1/PB2/PA8 (bonded)
  PA0 ──┤7       14├── PA10
  PA1 ──┤8       13├── PA9
  PA2 ──┤9       12├── VDD
  PA3 ──┤10      11├── VSS
        └──────────┘
```

## STM32 Pin Assignments

### USART1 (to CYD) - ACTIVE MODE
| Function | Pin | Package Pin |
|---|-----|---|
| USART1_TX | PA9 | 13 |
| USART1_RX | PA10 | 14 |

Note: These same pins are used by the system UART bootloader.

### USART1 (BOOTLOADER MODE) - Fixed by ST
| Function | Pin |
|---|-----|
| USART1_TX | PA9 |
| USART1_RX | PA10 |

Bootloader baud rate: auto-detected (send 0x7F sync byte)

### SPI1 (to MAX31855)
| Function | Pin | Package Pin |
|---|-----|---|
| SPI1_SCK | PA1 | 8 |
| SPI1_MISO | PA11 | 15 |
| CS (GPIO) | PA0 | 7 |

Note: MAX31855 is read-only, no MOSI needed.

### Other
| Function | Pin | Package Pin |
|---|-----|---|
| Relay/SSR | PA2 | 9 |
| SWDIO | PA13 | 17 |
| SWCLK | PA14 | 18 |
| BOOT0 | PA14 | 18 (shared with SWCLK) |

## Power Flow

```
AC Mains
    │
    ▼
┌─────────┐
│HLK-5M05 │ (AC-DC PSU)
└────┬────┘
     │ 5V
     ├──────────────────► CYD P1 VIN (powers CYD)
     │
     ├──► AP2112K-3.3 LDO ──► 3.3V Rail
     │                           ├──► STM32 VDD
     │                           └──► MAX31855 VCC
     │
     └──► Relay coil supply (5V)
```

## 3.3V LDO Regulator

The power board generates its own 3.3V locally instead of receiving it from the CYD:

| Parameter | Value |
|---|---|
| Part | AP2112K-3.3TRG1 (Diodes Inc) |
| Package | SOT-23-5 |
| Input | 5V from HLK-5M05 |
| Output | 3.3V, 600mA max |
| Load | STM32 + MAX31855 (~55mA max) |
| Input cap | 1uF ceramic |
| Output cap | 1uF ceramic |

## UART Bootloader Programming

To update STM32 firmware from CYD over UART:

1. **Enter bootloader mode**:
   - **Software jump** (preferred): STM32 app firmware receives a "reboot to bootloader" UART command, then jumps to system memory. No extra GPIO needed.
   - **Hardware fallback**: Physical button on power board to force BOOT0 high during reset.

2. **UART protocol**: See AN3155 for commands

3. **Sync**: Send 0x7F byte, bootloader auto-detects baud rate

4. **Pins**: PA9 (TX) / PA10 (RX) — same pins used for application UART, so no rewiring needed

## Protection Circuits

### UART Series Resistors

**Problem**: The CYD's P1 connector shares UART0 (TX/RX) with the onboard CH340 USB-to-serial chip. When the CYD is programmed via USB, both the CH340 and STM32 can drive the same UART lines simultaneously, causing bus contention. Additionally, if the STM32 is unpowered while the CYD is connected, the CYD's TX signal can forward-bias the STM32's ESD clamp diodes and inject current into an unpowered chip.

**Solution**: Two 1K series resistors on the UART TX and RX lines, placed on the power board between the STM32 (PA9/PA10) and the P1 JST connector.

| Resistor | Location | Purpose |
|---|---|---|
| R_TX (1K) | STM32 PA9 → P1 RX pin | Limits current during bus contention with CH340 |
| R_RX (1K) | STM32 PA10 ← P1 TX pin | Limits current through STM32 ESD clamp diodes when STM32 unpowered |

1K is low enough to not affect UART signal integrity at typical baud rates (115200 baud), but high enough to limit contention current to ~3.3mA.

### 5V Backfeed Protection (P-FET Pass Transistor)

**Problem**: When the CYD is powered via USB (for programming/debugging) and the power board is unplugged from mains, the CYD's 5V USB supply can backfeed through the P1 VIN line into the HLK-5M05 output. This is undesirable -- the HLK-5M05 is not designed to have voltage applied to its output.

**Solution**: A P-channel MOSFET (AO3401 or SI2301, SOT-23) as a high-side pass transistor between the HLK-5M05 output and the 5V rail.

**Circuit**:
```
HLK-5M05 Output ──► P-FET Source
                     P-FET Drain ──► 5V Rail (to P1 VIN, LDO, relay)
                     P-FET Gate ──► 100K resistor to GND
                     Gate-to-Source: 100nF cap (Miller coupling suppression)
```

**How it works**:
- **Normal operation** (mains powered): HLK-5M05 outputs 5V on the source pin. Gate is pulled to GND via 100K resistor, so Vgs = -5V, turning the P-FET fully on. Voltage drop is near-zero (~27mV at 500mA with AO3401).
- **USB backfeed** (mains off): 5V appears on the drain (from CYD P1 VIN). The body diode is reverse-biased (anode on source/HLK side which is 0V, cathode on drain/5V-rail side). Gate is at GND, but Vgs = 0V (source is at 0V), so the FET is off. Current is blocked.
- **100nF gate-to-source cap**: Suppresses Miller coupling during USB contact bounce, preventing momentary gate voltage spikes from turning the FET on during cable insertion/removal.

### Why P-FET Over Schottky Diode

A Schottky diode would be simpler, but the CYD uses AMS1117-3.3 LDOs which have a relatively high dropout voltage (~1.1V). A Schottky diode's ~0.3V forward drop would reduce the 5V supply to ~4.7V, leaving only ~0.3V of headroom above the LDO's minimum input (3.3V + 1.1V = 4.4V). This is too tight for reliable operation, especially with tolerance and temperature variation.

The P-FET gives the full 5V to the CYD with negligible voltage drop (~27mV), preserving the full margin for the AMS1117-3.3 LDO.

## CYD Physical Dimensions

| Measurement | Size |
|---|---|
| PCB size | 101.5 × 54.9 mm |
| Display active area | 73.44 × 48.96 mm |
| Display diagonal | 3.5 inches |
| Resolution | 480 × 320 pixels |

## Relays

**Part**: Omron G5LE-1 (SPDT, 10A)

**Pinout**:
| Pin | Function |
|-----|---|
| 1 | COM (Common) |
| 2 | Coil (-) |
| 3 | NC (Normally Closed) |
| 4 | NO (Normally Open) |
| 5 | Coil (+) |

**Wiring**: Use NO contact (Pin 4) for fail-safe operation - relay de-energizes → heater OFF.

**Flyback Diode**: 1N4148WQ-13-F (SOD-123, Diodes Inc, AEC-Q101 qualified)

Datasheet: http://www.omron.com/ecb/products/pdf/en-g5le.pdf

## AC Input Protection

Decision: **Fuse + MOV only** (skip X2 cap and EMI choke for hobby project)

| Component | Decision | Reason |
|---|---|---|
| Fuse | **Yes** | Safety - prevents fire on short |
| MOV | **Yes** | Cheap surge protection |
| X2 Cap | Skip | HLK-5M05 has internal filtering |
| EMI Choke | Skip | Only needed for EMC compliance |

### Fuse

**Spec**: 0.5A 250VAC slow-blow (per HLK-5M05 datasheet)

| Component | Part | LCSC # |
|---|---|---|
| Fuse holder | Xucheng 5x20 clip (pair) | C3130 |
| Fuse | Littelfuse 0215.500MXP | C142839 |

KiCad footprint: `Fuse:Fuseholder_Clip-5x20mm_Littelfuse_111_Inline_P20.00x5.00mm_D1.05mm_Horizontal`

### MOV (Varistor)

**Part**: 10D561K (per HLK-5M05 datasheet recommendation)
- 10mm diameter
- 560V varistor voltage (for universal 100-240VAC input)

## Screw Terminals

**Part**: Phoenix Contact 1935161 (2-position, 5mm pitch)

| Type | Library | Name |
|---|---|---|
| Symbol | Connector | Screw_Terminal_01x02 |
| Footprint | TerminalBlock_Phoenix | TerminalBlock_Phoenix_MKDS-1,5-2_1x02_P5.00mm_Horizontal |

## CYD Cable Connectors

CYD uses 1.25mm pitch JST GH-compatible connectors. Only P1 is used (single cable).

### PCB Header (for power board)

| Part | LCSC # | Notes |
|---|---|---|
| JST SM04B-GHS-TB(LF)(SN) | C189895 | SMD, right-angle, genuine JST (x1) |

KiCad:
- Symbol: `Connector:Conn_01x04_Pin`
- Footprint: `Connector_JST:JST_GH_SM04B-GHS-TB_1x04-1MP_P1.25mm_Horizontal`

### Cables

LCSC doesn't stock pre-made cables. Order from:
- AliExpress: "1.25mm 4pin JST cable" (cheapest, various lengths)
- Amazon: "JST GH 4 pin cable" or "PicoBlade 4 pin"

## BOM Summary (LCSC Parts)

| Component | Part Number | LCSC # | Qty |
|---|---|---|-----|
| Fuse holder clips | Xucheng 5x20 | C3130 | 1 pair |
| Fuse 0.5A slow-blow | Littelfuse 0215.500MXP | C142839 | 1 |
| MOV | 10D561K | (search) | 1 |
| Flyback diode | 1N4148WQ-13-F | (search) | 2 |
| JST GH 4-pin header | SM04B-GHS-TB(LF)(SN) | C189895 | 1 |
| LDO 3.3V | AP2112K-3.3TRG1 | (search) | 1 |
| P-FET (backfeed protection) | AO3401 or SI2301 | (search) | 1 |
| Gate resistor | 100K 0402/0603 | (search) | 1 |
| Gate-source cap | 100nF 0402/0603 | (search) | 1 |
| UART series resistors | 1K 0402/0603 | (search) | 2 |

## Architecture Revision Under Consideration (Feb 2026)

Considering replacing the two-board CYD + STM32 design with a single-board approach using a bare ESP32-S3-WROOM module and a standalone SPI display.

### Problem with CYD Approach

The CYD (ESP32-3248S035C) has almost no free GPIO — only TX/RX on the P1 connector are available. This forced a two-MCU architecture (CYD + STM32) with UART protocol, bootloader flashing, and bus contention protection — significant complexity for a simple relay + thermocouple project.

### Proposed New Architecture

Single custom PCB with:
- **MCU**: ESP32-S3-WROOM (bare module, ~33 usable GPIOs)
- **Display**: 3.5" IPS SPI module with ST7796 controller + capacitive touch (lcdwiki.com MSP3525/3526)
- **No STM32** — ESP32-S3 handles everything directly (WiFi, display, relay, thermocouple)

### Display Module: 3.5" IPS SPI ST7796 (MSP3525/3526)

14-pin interface:

| Pin | Label | Interface | Function |
|-----|---|---|---|
| 1 | VCC | Power | 3.3V |
| 2 | GND | Power | Ground |
| 3 | LCD_CS | SPI | LCD chip select |
| 4 | LCD_RST | GPIO | LCD reset |
| 5 | LCD_RS | GPIO | Command/data select (DC) |
| 6 | SDI(MOSI) | SPI | Shared SPI data in |
| 7 | SCK | SPI | Shared SPI clock |
| 8 | LED | GPIO | Backlight control |
| 9 | SDO(MISO) | SPI | Shared SPI data out |
| 10 | CTP_SCL | I2C | Touch I2C clock |
| 11 | CTP_RST | GPIO | Touch reset |
| 12 | CTP_SDA | I2C | Touch I2C data |
| 13 | CTP_INT | GPIO | Touch interrupt |
| 14 | SD_CS | SPI | SD card chip select |

LCD and SD card share the SPI bus. Touch uses a separate I2C bus.

**Key specs:** ST7796U/S controller, FT6336U capacitive touch (I2C, 2-point), 320x480 IPS, 16.7M colors, 300 cd/m², 5V input (onboard level shifters). Module size ~55.5 x 98.0 mm.

### Why ST7796 and Not ILI9488

Several similar 3.5" SPI displays use the ILI9488 controller instead. Avoid these:

| Feature | ST7796 | ILI9488 |
|---|---|---|
| **SPI 16-bit color (RGB565)** | Yes | **No** — 18/24-bit only over SPI |
| **Bytes per pixel (SPI)** | 2 | 3 (33% slower) |
| **MISO tristate when CS high** | Yes | **No** — causes SPI bus conflicts |
| **Shared SPI with SD card** | Works fine | Problematic without workaround |
| **Max SPI clock** | 80 MHz | ~60 MHz |

The ILI9488's lack of 16-bit SPI color and broken MISO tristate make it a poor choice for a shared SPI bus design (LCD + SD card + MAX31855 thermocouple all on one bus).

### Display Sourcing

All ST7796 + capacitive touch modules below share the same 14-pin interface and are electrically interchangeable. LCDWIKI (MSP3525/3526) is the OEM reference design; the others are resellers or clones.

LCSC does not stock assembled display modules.

| Source | Price | Shipping | Link |
|---|---|---|---|
| **Hosyond (Amazon)** | ~$15-17 | Prime | [Amazon B0CMD7Y55M](https://www.amazon.com/Hosyond-320x480-Capacitive-ST7796U-Mega2560/dp/B0CMD7Y55M) |
| **Elecrow** | ~$16.90 | Varies | [elecrow.com](https://www.elecrow.com/3-5-ips-spi-lcd-capacitive-touch-module-st7796-driver-320-480-resolution.html) |
| **Waveshare** | ~$18.99 | Direct or Amazon | [waveshare.com](https://www.waveshare.com/3.5inch-capacitive-touch-lcd.htm) |
| **AliExpress generics** | ~$8-15 | 2-4 weeks | Search "3.5 ST7796 SPI capacitive touch" (verify not ILI9488) |
| **ProtoSupplies** | ~$19.95 | US domestic | [protosupplies.com](https://protosupplies.com/product/ips-35-st7796/) |

Documentation/examples:
- [Elecrow wiki](https://www.elecrow.com/wiki/3.5-inch_IPS_SPI_LCD_Capacitive_Touch_Display_Module_With_ST7796_Driver-320x480_Resolution_Arduino_Compatible.html) (ESP32, STM32, Arduino examples)
- [Waveshare wiki](https://www.waveshare.com/wiki/3.5inch_Capacitive_Touch_LCD) (ESP32, Pico, RPi examples)

### MCU Comparison

| | XIAO ESP32-C3 | XIAO ESP32-S3 | Bare ESP32-S3-WROOM |
|---|---|---|---|
| **Usable GPIOs** | 11 | 13 | ~33 |
| **Pins needed** | 15 | 15 | 15 |
| **Verdict** | Not enough (-4) | Barely fits with tricks (-2) | Plenty (+18 spare) |
| **UART debug** | Sacrificed | Sacrificed | Available |
| **WiFi** | 2.4GHz, single-core | 2.4GHz, dual-core | 2.4GHz, dual-core |
| **USB** | CH340 serial | Native USB-OTG | Native USB-OTG |
| **Cost** | ~$5 | ~$8 | ~$3 (module only) |
| **PCB effort** | Plug-in | Plug-in | Full breakout needed |

### ESP32 Module Comparison (Bare Modules)

Evaluated which ESP32 variant to use for the single-board design:

| | **ESP32-WROOM-32E** | **ESP32-S3-WROOM-1** | **ESP32-C6-WROOM-1** |
|---|---|---|---|
| **Usable GPIOs** | ~25 | ~36 | ~22 |
| **Spare after project** | ~10 | ~20 | ~7 |
| **CPU** | Dual-core Xtensa LX6 | Dual-core Xtensa LX7 | Single-core RISC-V |
| **Native USB** | No (needs CH340/CP2102) | Yes (OTG + Serial/JTAG) | Serial/JTAG only |
| **WiFi** | 802.11n | 802.11n | 802.11ax (WiFi 6) |
| **LCSC price (qty 1)** | ~$5 | ~$5.30 | ~$5 |
| **LCSC price (bulk)** | ~$2.55 | ~$3.46 | ~$3.24 |
| **Maturity** | Most mature | Mature, well supported | Newer, smaller community |

ESP32-C3 rejected — too tight on GPIOs (same problem as XIAO).
ESP32-S2 rejected — single-core (risky for WiFi + LVGL), being phased out.

**Decision: ESP32-S3-WROOM-1-N4R2** (4MB flash, 2MB PSRAM). Native USB eliminates the need for a USB-UART bridge chip. Dual-core gives headroom for WiFi + display. Plenty of spare GPIOs.

- LCSC: [ESP32-S3-WROOM-1-N4R2 (C2913203)](https://www.lcsc.com/product-detail/C2913203.html)

### ESP32-S3 USB & Debugging

The ESP32-S3 has a built-in USB Serial/JTAG controller — no external USB-UART bridge chip needed. GPIO19 (D-) and GPIO20 (D+) connect directly to a USB-C connector.

**USB circuit (per Espressif hardware design guidelines):**
```
ESP32-S3                          USB-C Connector
GPIO19 (D-) ──[22Ω]──┬────────── D-
                      (C to GND, optional footprint)
GPIO20 (D+) ──[22Ω]──┬────────── D+
                      (C to GND, optional footprint)
```

This provides:
- Serial programming/flashing
- Serial monitor (printf debugging)
- JTAG debugging (built-in, no external adapter needed)

ESP32 uses JTAG, not SWD (SWD is ARM Cortex-M specific). The built-in USB-JTAG is sufficient for most development. Dedicated JTAG pins (GPIO44/45/47/48) are also available for external adapters if needed.

Reference design: [ESP32-S3 Hardware Design Guidelines - Schematic Checklist](https://docs.espressif.com/projects/esp-hardware-design-guidelines/en/latest/esp32s3/schematic-checklist.html)

### Pin Budget (15 signals required)

| Signal | Bus | Notes |
|---|-----|---|
| SPI SCK | SPI (shared) | LCD + SD card + MAX31855 |
| SPI MOSI | SPI (shared) | |
| SPI MISO | SPI (shared) | |
| LCD_CS | GPIO | |
| LCD_RS/DC | GPIO | |
| LCD_RST | GPIO | Could tie to 3.3V via RC to save a pin |
| LED (backlight) | GPIO | Could tie to 3.3V (always on) to save a pin |
| SD_CS | GPIO | |
| I2C SDA | I2C | Capacitive touch |
| I2C SCL | I2C | Capacitive touch |
| CTP_RST | GPIO | Could tie to 3.3V to save a pin |
| CTP_INT | GPIO | Could poll instead to save a pin |
| MAX31855_CS | GPIO | Thermocouple SPI chip select |
| Relay | GPIO | SSR/relay drive |
| (spare) | — | ESP32-S3-WROOM has ~18 pins remaining |

### Benefits Over Current CYD Design

- **One MCU** instead of two — eliminates STM32, UART protocol, bootloader complexity
- **One board** instead of two — simpler assembly, lower cost
- **No bus contention** — no CH340 fighting STM32 on shared UART
- **No backfeed protection needed** — no P-FET circuit required (USB powers ESP32 directly)
- **Full GPIO flexibility** — 18+ spare pins for expansion (buzzer, LEDs, extra sensors)
- **Single firmware** — one codebase, one flash target

### Trade-offs

- Lose CYD's pre-built form factor and enclosure
- More PCB design work (ESP32 antenna keep-out, USB-C, boot/reset buttons)
- Lose independent fail-safe MCU (mitigated by ESP32 watchdog timer)

### Decision Status

**Decided: ESP32-S3-WROOM-1-N4R2 single-board design.**

### References

- Display (OEM reference): https://www.lcdwiki.com/3.5inch_IPS_SPI_Module_ST7796
- ESP32-S3 hardware design guidelines: https://docs.espressif.com/projects/esp-hardware-design-guidelines/en/latest/esp32s3/schematic-checklist.html
- ESP32-S3 JTAG debugging: https://docs.espressif.com/projects/esp-idf/en/stable/esp32s3/api-guides/jtag-debugging/index.html
- ESP32-S3 USB Serial/JTAG: https://docs.espressif.com/projects/esp-idf/en/latest/esp32s3/api-guides/usb-serial-jtag-console.html
- ESP32-S3 pin reference: https://www.atomic14.com/2023/11/21/esp32-s3-pins
- XIAO ESP32-C3: https://wiki.seeedstudio.com/XIAO_ESP32C3_Getting_Started/
- XIAO ESP32-S3: https://wiki.seeedstudio.com/xiao_esp32s3_getting_started/

## References

- CYD Pinout: https://github.com/witnessmenow/ESP32-Cheap-Yellow-Display/blob/main/PINS.md
- CYD Specs: https://www.espboards.dev/esp32/cyd-esp32-3248s035/
- STM32G031 Datasheet: https://www.st.com/resource/en/datasheet/stm32g031c6.pdf
- AN2606 - STM32 boot modes: https://www.st.com/resource/en/application_note/cd00167594-stm32-microcontroller-system-memory-boot-mode-stmicroelectronics.pdf
- AN3155 - UART bootloader protocol: https://www.st.com/resource/en/application_note/an3155-usart-protocol-used-in-the-stm32-bootloader-stmicroelectronics.pdf
- Omron G5LE-1 Datasheet: http://www.omron.com/ecb/products/pdf/en-g5le.pdf
- macsbug CYD info: https://macsbug.wordpress.com/2022/10/02/esp32-3248s035/

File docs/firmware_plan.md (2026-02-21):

# Firmware Plan

*Written February 2026 — covers remaining work to get the single-board ESP32-S3 design to a working state.*

> **Status: ALL PHASES COMPLETE** (February 2026)
> See [firmware_architecture.md](firmware_architecture.md) for documentation of the implemented system.

---

## Final State

All 7 phases implemented. Firmware is feature-complete pending hardware bring-up.

| File | State | Notes |
|---|---|---|
| `crockpot.c` | **Done** | State machine, mutex, safety shutoff, sensor watchdog, alert callback, TWDT |
| `temperature.c` | **Done** | MAX31855 SPI driver, fault decoding |
| `relay.c` | **Done** | GPIO relay control, active-high/low configurable via Kconfig |
| `wifi.c` | **Done** | STA mode, event-driven, retry logic, NVS credentials |
| `telegram.c` | **Done** | Long-polling, commands, NVS token, chat ID whitelist, alert queue |
| `nvs_config.c` | **Done** | Shared NVS helpers for wifi + telegram |
| `spi_bus.c` | **Done** | Shared SPI2 bus init |
| `display_driver.c` | **Done** | ST7796 SPI driver via esp_lcd |
| `touch_driver.c` | **Done** | FT6336U I2C driver via esp_lcd_touch_ft5x06 |
| `display.c` | **Done** | LVGL init, lvgl_port setup, display + touch registration |
| `gui.c` | **Done** | Full LVGL UI: 4 screens, arc indicator, buttons, status bar, toast overlay |
| `Kconfig.projbuild` | **Done** | All GPIO and credential config options |
| `idf_component.yml` | **Done** | LVGL v9, esp_lvgl_port v2, esp_lcd_st7796, esp_lcd_touch_ft5x06 |
| `display_hal.c/.h` | **Deleted** | Replaced by LVGL + esp_lcd |
| `touch_hal.c/.h` | **Deleted** | Replaced by esp_lcd_touch |

---

## Original State Assessment (at plan time)

### What was implemented and working

| File | State | Notes |
|---|---|---|
| `crockpot.c` | **Done** | State machine, mutex, safety shutoff, sensor watchdog |
| `temperature.c` | **Done** | Full MAX31855 SPI driver, fault decoding |
| `relay.c` | **Done** | GPIO relay control, active-high/low configurable |
| `wifi.c` | **Done** | STA mode, event-driven, retry logic, IP retrieval |
| `telegram.c` | **Done** | Long-polling, all commands (/status /off /warm /low /high), sendMessage |
| `gui.c` | **Good structure** | Full UI logic: 4 screens, touch zones, dimming, themes — but calls stub HAL |
| `display.c` | **Partial** | Physical button ISR works; display rendering is a stub |
| `display_hal.c` | **Stub** | All TODO — no real SPI driver |
| `touch_hal.c` | **Stub** | All TODO — returns no events |

### Known TODOs / gaps

1. **NVS storage** — WiFi SSID/password and Telegram token are both commented `// TODO: Load from NVS`. Currently falls back to `sdkconfig` defaults, so first-time provisioning requires a reflash.
2. **GPIO pin assignments are stale** — `relay.h` and `temperature.h` reference "XIAO ESP32-C3" pin numbers. Need updating for the ESP32-S3 single-board design.
3. **Display stack is completely unimplemented** — `display_hal.c` and `touch_hal.c` are empty stubs. No pixels will appear on screen.
4. **`uart_master.c` was never written** — the STM32 UART layer from the old two-board design was never implemented. This is fine; the architecture has moved to single-board and that layer is no longer needed.
5. **WARM/LOW/HIGH are all identical** — `relay_apply_state()` turns one relay ON for all three heat states. Differentiation (e.g., duty-cycle PWM) is a future enhancement.
6. **No watchdog configured** — `esp_task_wdt` is imported in `main.c` but never initialized. Safety relies solely on software checks in the control loop.

---

## Architecture Decision: Adopt LVGL

The existing `display_hal.h` is a custom drawing API that re-invents what LVGL already provides — and better. Rather than implementing that stub from scratch, replace it with LVGL.

**LVGL** (Light and Versatile Graphics Library) is the de-facto embedded UI library for ESP32, with first-class ESP-IDF support via Espressif's component ecosystem:

| Component | Role |
|---|---|
| `lvgl/lvgl` | Core graphics library |
| `espressif/esp_lvgl_port` | Bridges LVGL to ESP-IDF (tick timer, display flush, touch read) |
| `espressif/esp_lcd_st7796` (or built-in) | SPI display panel driver for ST7796 |
| `espressif/esp_lcd_touch_ft5x06` | I2C touch driver — FT6336U is FT5x06 family-compatible |

ESP-IDF v5.x includes `esp_lcd` natively. `esp_lcd_new_panel_st7796()` and the FT5x06 touch driver are available via `idf_component_manager` (`idf_component.yml`).

### What changes with LVGL

| Old | New |
|-----|-----|
| `display_hal.c` (stub) | Deleted — replaced by `esp_lcd` ST7796 flush driver |
| `touch_hal.c` (stub) | Deleted — replaced by `esp_lcd_touch` FT6336U driver |
| `display_hal.h` | Deleted — LVGL is the abstraction layer |
| `touch_hal.h` | Deleted |
| `gui.c` | Rewritten using LVGL widgets (`lv_label`, `lv_btn`, `lv_arc`, etc.) |
| `display.c` | Becomes the LVGL init + display task entry point |

`crockpot.c`, `temperature.c`, `relay.c`, `wifi.c`, and `telegram.c` are **not affected**.

---

## Proposed GPIO Assignments (ESP32-S3-WROOM-1-N4R2)

*Subject to PCB layout review — finalize when schematic is started.*

Constraints:
- GPIO19/20 are fixed for USB D-/D+
- GPIO26-32: PSRAM (N4R2 variant) — avoid
- GPIO33-37: Flash — avoid
- GPIO0, GPIO3, GPIO45, GPIO46: strapping pins — avoid or use carefully

| Signal | GPIO | Notes |
|---|---|---|
| SPI SCK | 12 | Shared bus (LCD + SD + MAX31855) |
| SPI MOSI | 11 | Shared |
| SPI MISO | 13 | Shared |
| LCD_CS | 10 | ST7796 chip select |
| LCD_DC | 9 | Command/data select |
| LCD_RST | 8 | Can tie to EN via RC to save pin |
| LCD_BL | 47 | Backlight PWM (or tie to 3.3V, always on) |
| SD_CS | 2 | Optional (future use) |
| Touch SDA | 5 | I2C, FT6336U |
| Touch SCL | 4 | I2C, FT6336U |
| CTP_RST | 6 | Can tie high via 10K to save pin |
| CTP_INT | 7 | Touch interrupt (or poll, saves pin) |
| MAX31855_CS | 16 | Thermocouple SPI chip select |
| Relay | 17 | SSR/relay drive output |
| USB D- | 19 | Fixed by ESP32-S3 |
| USB D+ | 20 | Fixed by ESP32-S3 |
| BOOT | 0 | Standard ESP32-S3 boot button |

GPIO budget: 15 signals used, ~18 spare (1, 14, 15, 18, 21, 38-44, 48).

---

## Phase Plan

### Phase 1 — GPIO Pin Assignments & Kconfig ✓ DONE

**Goal:** Replace hardcoded XIAO ESP32-C3 pin numbers with correct ESP32-S3 values, moved to `Kconfig` so they're configurable without touching source code.

**Files to change:**
- `temperature.h` — replace hardcoded `MAX31855_PIN_*` defines with `CONFIG_*` Kconfig symbols
- `relay.h` — replace `RELAY_MAIN_GPIO` / `RELAY_AUX_GPIO` with Kconfig symbols
- New file: `Kconfig.projbuild` (or `main/Kconfig`) — defines all GPIO config options with sensible defaults

**Kconfig sections needed:**
```
menu "IoT Crockpot Hardware"

    menu "SPI Bus"
        config CROCKPOT_SPI_SCK ... default 12
        config CROCKPOT_SPI_MOSI ... default 11
        config CROCKPOT_SPI_MISO ... default 13
    endmenu

    menu "Display (ST7796)"
        config CROCKPOT_LCD_CS ... default 10
        config CROCKPOT_LCD_DC ... default 9
        config CROCKPOT_LCD_RST ... default 8
        config CROCKPOT_LCD_BL ... default 47
    endmenu

    menu "Touch (FT6336U)"
        config CROCKPOT_TOUCH_SDA ... default 5
        config CROCKPOT_TOUCH_SCL ... default 4
        config CROCKPOT_TOUCH_RST ... default 6
        config CROCKPOT_TOUCH_INT ... default 7
    endmenu

    menu "MAX31855 Thermocouple"
        config CROCKPOT_TC_CS ... default 16
    endmenu

    menu "Relay"
        config CROCKPOT_RELAY_GPIO ... default 17
    endmenu

endmenu
```

---

### Phase 2 — NVS Provisioning ✓ DONE

**Goal:** WiFi credentials and Telegram token loaded from NVS at boot, with a provisioning flow when not set.

**Files to change:**
- `wifi.c` — `wifi_connect()` reads SSID/password from NVS; `wifi_set_credentials()` writes to NVS
- `telegram.c` — `telegram_init()` reads token from NVS; `telegram_set_token()` writes to NVS

**Provisioning flow options (pick one):**

| Option | Pros | Cons |
|---|---|---|
| **Serial provisioning** | Simple — send JSON over USB serial at first boot | Requires USB cable |
| **Touchscreen provisioning** | No cable needed, on-device UI | Needs keyboard widget (complex) |
| **Hardcoded in sdkconfig** | Fastest to get running | Credentials in source tree, need reflash to change |

**Recommendation for now:** Hardcode in `sdkconfig` via `menuconfig` (already partially working), and add NVS write/read as a Phase 2 polish item. The TODOs are already in place.

**New file:** `nvs_config.c/.h` — shared NVS helper (open namespace, read/write string wrappers) used by both `wifi.c` and `telegram.c`.

---

### Phase 3 — ST7796 SPI Display Driver ✓ DONE

**Goal:** Implement a real display driver using `esp_lcd`.

**Approach:** Use `esp_lcd_new_panel_st7796()` from `espressif/esp_lcd_st7796` IDF component. This provides the init sequence and pixel write commands; we just configure the SPI bus and panel.

**Key steps:**
1. Create SPI bus (`spi_bus_initialize`) — shared with MAX31855
2. Create `esp_lcd_io_handle_t` for the ST7796 panel over SPI
3. Call `esp_lcd_new_panel_st7796()` to get a `esp_lcd_panel_handle_t`
4. Run panel init sequence, set orientation (landscape: 480×320)
5. Expose a `flush_cb` function that LVGL calls when it wants to push pixels

**File:** `display_hal.c` is deleted. A new `display_driver.c` (or the logic moves into `display.c`) handles the above.

**ST7796 SPI config notes:**
- Clock: up to 80 MHz supported, start at 40 MHz for stability
- Mode: SPI Mode 0 (CPOL=0, CPHA=0)
- Shares SPI bus with MAX31855 (different CS pins, no conflict)
- MAX31855 is SPI Mode 0 as well — no mode-switching needed

---

### Phase 4 — FT6336U Touch Driver ✓ DONE

**Goal:** Read touch coordinates from the FT6336U over I2C.

**Approach:** Use `espressif/esp_lcd_touch_ft5x06` IDF component. The FT6336U is register-compatible with the FT5x06 family.

**Key steps:**
1. Create I2C bus (`i2c_master_init`) on SDA/SCL pins
2. Call `esp_lcd_touch_new_i2c_ft5x06()` to get a `esp_lcd_touch_handle_t`
3. Expose a `read_cb` function that LVGL calls for touch input

**FT6336U I2C notes:**
- Address: 0x38
- CTP_INT pin: configure as GPIO input interrupt for efficient polling (vs. polling in a tight loop)
- CTP_RST: pulse low to reset on init

---

### Phase 5 — LVGL Integration ✓ DONE

**Goal:** Wire the ST7796 display driver and FT6336U touch driver into LVGL using `esp_lvgl_port`.

**Steps:**
1. Add `idf_component.yml` to declare dependencies:
   ```yaml
   dependencies:
     lvgl/lvgl: "^9.0.0"
     espressif/esp_lvgl_port: "^2.0.0"
     espressif/esp_lcd_st7796: "*"
     espressif/esp_lcd_touch_ft5x06: "*"
   ```
2. Init LVGL via `lvgl_port_init()`
3. Register display: `lvgl_port_add_disp()` with the ST7796 panel handle and a DMA draw buffer
4. Register touch: `lvgl_port_add_touch()` with the FT6336U touch handle
5. LVGL tick is handled automatically by `esp_lvgl_port`

**Draw buffer sizing:**
- Full-screen buffer (480×320×2 = 300KB) is too large for internal RAM
- Use partial buffer: 1/10 screen = 480×32×2 = ~30KB (fits in internal SRAM)
- PSRAM option: 2MB PSRAM on N4R2 — could use full double-buffer for tear-free rendering

**File changes:**
- `display.c` — becomes the LVGL init + `lvgl_port` setup; starts LVGL task
- `display_hal.h/.c` — deleted
- `touch_hal.h/.c` — deleted
- `CMakeLists.txt` — remove `display_hal.c`, `touch_hal.c`; add `idf_component.yml`

---

### Phase 6 — GUI Rewrite with LVGL ✓ DONE

**Goal:** Rewrite `gui.c` using LVGL widgets, replacing the custom drawing primitives.

**Main screen layout (480×320, landscape):**

```
┌─────────────────────────────────────────────────────┐
│                                                     │
│              ◉  LOW                                 │
│         (state indicator arc)                       │
│                                                     │
│              142.5 °F                               │
│                                                     │
│   ┌────────┐  ┌────────┐  ┌────────┐  ┌────────┐   │
│   │  OFF   │  │  WARM  │  │  LOW   │  │  HIGH  │   │
│   └────────┘  └────────┘  └────────┘  └────────┘   │
│                                                     │
│  WiFi ●           00:42          ⚙  ℹ              │
└─────────────────────────────────────────────────────┘
```

**LVGL widgets to use:**

| UI Element | LVGL Widget |
|---|---|
| State display | `lv_label` + `lv_arc` (color coded) |
| Temperature | `lv_label` (large font) |
| Heat buttons (OFF/WARM/LOW/HIGH) | `lv_btn` array, highlight active |
| Status bar | `lv_label` (WiFi, uptime) |
| Settings icon | `lv_btn` → navigate to settings screen |
| Screen transitions | `lv_screen_load_anim()` |
| Message toasts | `lv_msgbox` or custom `lv_obj` popup |

**Screens:**
1. **Main** — temperature + state display + heat level buttons
2. **Settings** — C/F toggle, brightness slider, screen timeout
3. **WiFi** — connection status, SSID, IP address
4. **Info** — uptime, firmware version

**Theme:** Dark background, color-coded state (gray=OFF, yellow=WARM, orange=LOW, red=HIGH).

**File changes:**
- `gui.c` — complete rewrite using LVGL API
- `gui.h` — simplify public API (mostly `gui_init`, `gui_start`, `gui_show_message`)
- `display.c` — remove old button ISR if physical buttons not needed; or keep as an input device registered with LVGL

---

### Phase 7 — Watchdog & Hardening ✓ DONE

**Goal:** Add remaining safety infrastructure.

1. **Task watchdog timer** — enable `esp_task_wdt`, register control task. If control loop hangs for >5s, trigger restart.
2. **Error counts / Telegram alerts** — send a Telegram message on auto-shutoff event (temperature limit hit, sensor error shutoff). Already have the infrastructure; just need to hook it up in `crockpot.c`.
3. **Relay active-low option** — verify `RELAY_ACTIVE_HIGH` matches actual hardware (SSR modules are often active-low).
4. **Boot log** — log chip info, IDF version, firmware version, and all configured GPIO pins at startup. Helpful for debugging.

---

## Summary: Files Affected

| File | Action |
|---|---|
| `main/Kconfig` | **New** — GPIO config options |
| `nvs_config.c/.h` | **New** — NVS helpers for wifi + telegram |
| `display_driver.c/.h` | **New** — ST7796 SPI init via esp_lcd |
| `touch_driver.c/.h` | **New** — FT6336U I2C init via esp_lcd_touch |
| `idf_component.yml` | **New** — LVGL + esp_lvgl_port + driver deps |
| `display.c` | **Rewrite** — LVGL init, lvgl_port setup, task |
| `gui.c` | **Rewrite** — LVGL widgets instead of display_hal calls |
| `gui.h` | **Simplify** — trim public API |
| `temperature.h` | **Update** — GPIO defines → Kconfig symbols |
| `relay.h` | **Update** — GPIO defines → Kconfig symbols |
| `wifi.c` | **Update** — NVS credential load/store |
| `telegram.c` | **Update** — NVS token load/store |
| `CMakeLists.txt` | **Update** — add new files, remove deleted files |
| `display_hal.c/.h` | **Delete** — replaced by LVGL |
| `touch_hal.c/.h` | **Delete** — replaced by esp_lcd_touch |
| `interface_blynk.c/.h` | **Defer** — Blynk interface, not needed for MVP |

---

## Open Questions

1. **GPIO pin assignments** — Proposed above, but finalize against the PCB schematic when started. Kconfig makes it easy to change without source edits.
2. **LVGL version** — v8 vs v9. v9 has API changes. `esp_lvgl_port` v2.x supports LVGL v9. Check latest stable version at implementation time.
3. **PSRAM for display buffer** — The N4R2 has 2MB PSRAM. Using it for a full double-buffer (2 × 300KB) would eliminate tearing. Trade-off: slightly more complex init. Recommended to try.
4. **Physical buttons** — `display.c` has a working GPIO ISR for up/down/select buttons. With a touchscreen these are redundant, but keeping them as a fallback is low cost. Decide at PCB layout time whether to include them.
5. **WiFi provisioning UX** — How should a user configure WiFi credentials on a fresh board? Options: serial JSON, BLE provisioning, or touchscreen keyboard. Defer to after MVP is working.
6. **Telegram security** — Currently any chat ID can control the crockpot. A whitelist of allowed chat IDs should be added (store in NVS alongside the token).

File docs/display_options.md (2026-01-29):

# Display Options for IoT Crockpot

This document lists potential display options for the crockpot controller, ranging from full touchscreen displays to budget alternatives.

## Requirements

- Size: 2-4 inches
- Touch: Resistive or capacitive (see comparison below)
- Interface: SPI for display, SPI or I2C for touch
- Voltage: 3.3V compatible (ESP32-C3)
- Budget: As cheap as practical

## Resistive vs Capacitive Touch

| Feature | Resistive | Capacitive |
|---|---|---|
| **Price** | $3-8 | $10-18 |
| **Responsiveness** | Good | Excellent |
| **Pressure required** | Yes | No (hover works) |
| **Multi-touch** | No | Yes (some) |
| **Stylus/gloves** | Works | Usually no |
| **Durability** | Can wear out | Very durable |
| **Interface** | SPI (XPT2046) | I2C (FT6236) |
| **Extra pins needed** | 2 (shares SPI) | 2-3 (separate I2C) |

**For a crockpot:** Resistive is likely fine - simple UI, occasional use, and much cheaper.

---

## Option 1: All-in-One ESP32 + Display Boards

These replace the XIAO ESP32-C3 with an integrated solution.

| Product | Size | Resolution | Touch | Price | Notes |
|---|---|---|---|---|---|
| ESP32-2432S028 "CYD" (Capacitive) | 2.8" | 320x240 | Capacitive | $12-18 | Huge community support |
| ESP32-2432S028R "CYD" (Resistive) | 2.8" | 320x240 | Resistive | $10-15 | Cheaper but less responsive |
| ESP32-2432S024 | 2.4" | 320x240 | Resistive | $10-14 | Smaller form factor |

**Pros:**
- Simplest integration (no wiring)
- Well documented
- Includes WiFi/BT, SD card slot, RGB LED

**Cons:**
- Replaces existing XIAO ESP32-C3
- Locked to ESP32-WROOM-32 (not C3)

**Links:**
- [CYD GitHub Community](https://github.com/witnessmenow/ESP32-Cheap-Yellow-Display)
- [Random Nerd Tutorials Guide](https://randomnerdtutorials.com/cheap-yellow-display-esp32-2432s028r/)

---

## Option 2: Resistive Touch TFT Modules (CHEAPEST TOUCHSCREEN)

Resistive touch is cheaper than capacitive. Uses XPT2046 controller over SPI.

| Product | Size | Resolution | Driver | Touch IC | Price | Link |
|---|---|---|---|---|---|---|
| ILI9341 + XPT2046 | 2.4" | 240x320 | ILI9341 | XPT2046 | **$3-5** | [AliExpress](https://www.aliexpress.com/w/wholesale-ili9341-xpt2046.html) |
| ILI9341 + XPT2046 | 2.8" | 240x320 | ILI9341 | XPT2046 | **$4-7** | [AliExpress](https://www.aliexpress.com/item/32617643223.html) |
| ILI9341 + XPT2046 | 3.2" | 240x320 | ILI9341 | XPT2046 | **$5-8** | [AliExpress](https://www.aliexpress.com/i/4000127496421.html) |
| ST7796 + XPT2046 | 3.5" | 320x480 | ST7796 | XPT2046 | **$6-10** | AliExpress |

**Interface:**
- Display: SPI (MOSI, CLK, CS, DC, RST)
- Touch: SPI (MOSI, CLK, T_CS, T_IRQ) - shares MOSI/CLK with display

**Pros:**
- **Cheapest full touchscreen option**
- Single SPI bus for both display and touch
- Well supported in ESP-IDF and Arduino
- Works with stylus or finger

**Cons:**
- Less responsive than capacitive
- Requires pressure (not hover-sensitive)
- Can wear out over time
- Not multi-touch

**XPT2046 Notes:**
- 12-bit ADC for touch position
- SPI interface (up to 2MHz)
- IRQ pin goes low when touched
- Shares SPI bus with display (different CS pins)

---

## Option 3: Capacitive Touch TFT Modules

More responsive than resistive, but pricier. Uses I2C touch controllers.

### 2.8" Displays

| Product | Resolution | Driver | Touch IC | Price | Link |
|---|---|---|---|---|---|
| Elecrow 2.8" IPS Capacitive | 240x320 | ILI9341 | FT6236 | ~$11 | [Elecrow](https://www.elecrow.com/2-8-ips-spi-lcd-capacitive-touch-module-ili9341-driver-240-320-resolution.html) |
| Generic ILI9341 + Cap Touch | 240x320 | ILI9341 | FT6236 | $8-12 | AliExpress |

### 3.5" Displays

| Product | Resolution | Driver | Touch IC | Price | Link |
|---|---|---|---|---|---|
| Elecrow 3.5" IPS Capacitive | 320x480 | ST7796 | FT6336 | ~$17 | [Elecrow](https://www.elecrow.com/3-5-ips-spi-lcd-capacitive-touch-module-st7796-driver-320-480-resolution.html) |
| Waveshare 3.5" Capacitive | 320x480 | ST7796S | FT6336U | ~$15 | [Waveshare](https://www.waveshare.com/3.5inch-capacitive-touch-lcd.htm) |

**Interface (typical):**
- Display: SPI (4-5 pins: MOSI, CLK, CS, DC, RST)
- Touch: I2C (2 pins: SDA, SCL + INT optional)

**Pros:**
- Keep existing XIAO ESP32-C3
- IPS displays have good viewing angles

**Cons:**
- More wiring required
- Uses more GPIO pins

---

## Option 4: Standalone Capacitive Touch Panels (Overlay)

Separate touch panel to pair with any LCD. Cheapest capacitive option.

| Product | Size | Controller | Interface | Price | Link |
|---|---|---|---|---|---|
| AliExpress FT6236 Panel | 3.5" | FT6236 | I2C | ~$5-6 | [AliExpress](https://www.aliexpress.com/item/32814164683.html) |
| BuyDisplay 2.3" Panel | 2.3" | FT6236 | I2C | $5-10 | [BuyDisplay](https://www.buydisplay.com/2-3-inch-capacitive-touch-panel-screen-with-controller-ft6236) |
| BuyDisplay 3.2" Panel | 3.2" | FT6236 | I2C | $5-10 | [BuyDisplay](https://www.buydisplay.com/3-2-inch-capacitive-touch-panel-wiith-controller-ft6236-for-240x320-dots) |
| BuyDisplay 3.5" Panel | 3.5" | FT6236 | I2C | $5-10 | [BuyDisplay](https://www.buydisplay.com/3-5-inch-capacitive-touch-panel-wiith-controller-ft6236-for-320x480-dots) |

**Pros:**
- Cheapest capacitive touch option
- Pair with any matching LCD
- Simple I2C interface

**Cons:**
- Must match panel size to LCD exactly
- Alignment/mounting more complex
- Need separate LCD purchase

---

## Option 5: Capacitive Touch Buttons (No Screen Touch)

Use discrete touch buttons instead of touchscreen. Display is view-only.

| Product | Channels | Interface | Price | Link |
|---|---|---|---|---|
| TTP223 Touch Sensor | 1 | GPIO | $0.20-0.30 ea | [Amazon](https://www.amazon.com/ALAMSCN-TTP223-Capacitive-Locking-Arduino/dp/B0BNHM7TQH) |
| TTP229 Touch Keypad | 16 | I2C/Serial | $2-4 | AliExpress |
| MPR121 Breakout | 12 | I2C | $3-6 | AliExpress |
| CAP1188 Breakout | 8 | I2C | $5-8 | Adafruit |

**Example Setup:**
- 3-4x TTP223 buttons: UP, DOWN, SELECT, POWER
- Cheap non-touch OLED or LCD for display
- Total: ~$5-8 for display + $1-2 for buttons

**Pros:**
- Cheapest overall solution (~$6-10 total)
- Dead simple to program
- Very reliable

**Cons:**
- No dynamic touch UI
- Fixed button positions
- Less "modern" feel

---

## Option 6: Non-Touch Displays (Reference)

If touch isn't required, these are the cheapest display options.

| Product | Size | Resolution | Interface | Price |
|---|---|---|---|---|
| SSD1306 OLED | 0.96" | 128x64 | I2C | $2-4 |
| SSD1306 OLED | 1.3" | 128x64 | I2C/SPI | $3-5 |
| SH1106 OLED | 1.3" | 128x64 | I2C | $3-5 |
| SSD1309 OLED | 2.42" | 128x64 | I2C/SPI | $8-12 |
| ST7789 TFT | 1.3" | 240x240 | SPI | $3-5 |
| ST7789 TFT | 2.0" | 240x320 | SPI | $4-6 |
| ILI9341 TFT | 2.4" | 240x320 | SPI | $5-8 |

**Pros:**
- Extremely cheap
- Simple wiring
- Low power (especially OLED)

**Cons:**
- No touch capability
- Requires physical buttons for input

---

## Cost Comparison Summary

| Approach | Total Cost | Touch Type | Complexity |
|---|---|---|---|
| **2.4" Resistive TFT (ILI9341+XPT2046)** | **$3-5** | Resistive | Low |
| **2.8" Resistive TFT (ILI9341+XPT2046)** | **$4-7** | Resistive | Low |
| TTP223 buttons + OLED | $4-7 | Buttons | Low |
| TTP223 buttons + 2.4" TFT | $6-10 | Buttons | Low |
| CYD Resistive (ESP32-2432S028R) | $10-15 | Resistive | Low |
| 2.8" Capacitive TFT | $11-17 | Capacitive | Medium |
| CYD Capacitive | $12-18 | Capacitive | Low |

---

## Recommended Options

### Cheapest Touchscreen: 2.8" Resistive TFT (~$5)
- ILI9341 display + XPT2046 touch controller
- Full touchscreen for the price of a basic display
- Good enough for simple UI (buttons, sliders)
- [AliExpress ILI9341+XPT2046](https://www.aliexpress.com/w/wholesale-ili9341-xpt2046.html)

### Budget Non-Touch: TTP223 + 1.3" OLED (~$6)
- 3x TTP223 touch buttons (UP/DOWN/SELECT)
- 1.3" SH1106 OLED display
- Simple, reliable, very cheap

### Best Touch Experience: 2.8" Capacitive TFT (~$11)
- Elecrow or generic ILI9341 + FT6236 module
- Smooth, responsive touch
- Good size for kitchen visibility

### Easiest Integration: CYD Resistive ($10-15)
- ESP32-2432S028R with resistive touch
- No wiring, huge community
- Replaces XIAO (trade-off)

---

## Technical Notes

### Common Touch Controllers

**Resistive (cheaper):**
- **XPT2046**: Most common resistive controller, SPI interface, 12-bit ADC

**Capacitive (more responsive):**
- **FT6236/FT6336**: Most common capacitive, I2C, single/dual touch
- **GT911**: Multi-touch (5-10 points), I2C
- **CST816S**: Low power, I2C, common on smartwatches

### ESP32-C3 GPIO Constraints
The XIAO ESP32-C3 has limited GPIOs (11 usable). Plan pin usage carefully.

| Function | Pins Required | Notes |
|---|---|---|
| SPI Display | 5 (MOSI, CLK, CS, DC, RST) | |
| XPT2046 Resistive Touch | 2 (T_CS, T_IRQ) | Shares MOSI/CLK with display |
| I2C Capacitive Touch | 2-3 (SDA, SCL, INT) | Separate bus from SPI |
| TTP223 Buttons | 1 per button | Simple GPIO input |

**Resistive touch advantage:** Shares SPI bus with display, only needs 2 extra pins (T_CS, T_IRQ).

**XIAO ESP32-C3 Available Pins:**
- D0-D10 (11 GPIOs total)
- D4/D5 are default I2C (SDA/SCL)
- D8/D9/D10 are default SPI (SCK/MISO/MOSI)

### Display Driver Libraries (ESP-IDF)
- **LVGL**: Full-featured GUI library, supports touch
- **TFT_eSPI**: Arduino-style, easy setup
- **esp_lcd**: ESP-IDF native, lower level

---

## Next Steps

1. Decide on touch approach (full screen vs buttons)
2. Order samples of top 2 choices
3. Prototype with simulator first
4. Update PCB design for chosen display

---

*Last updated: 2025-01-28*

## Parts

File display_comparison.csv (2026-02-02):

Model | Size (inches) | Resolution | Display Type | Touch Type | ESP32 Built-in | Approx Price (USD) | Color/Mono | Notes | Source
ESP32-2432S024R (CYD 2.4) | 2.4 | 240x320 | TFT ILI9341 | Resistive | Yes (WROOM-32) | $10-12 | Color | Smallest CYD variant same features as 2.8 | AliExpress
ESP32-2432S028R (CYD 2.8) | 2.8 | 240x320 | TFT ILI9341 | Resistive | Yes (WROOM-32) | $10-15 | Color | Most popular "Cheap Yellow Display" huge community support | AliExpress/Amazon
ESP32-2432S028C (CYD 2.8 Cap) | 2.8 | 240x320 | TFT ILI9341 | Capacitive | Yes (WROOM-32) | $12-18 | Color | Capacitive version of CYD slightly more expensive | AliExpress
ESP32-3248S035R (CYD 3.5) | 3.5 | 320x480 | TFT ST7796 | Resistive | Yes (WROOM-32) | $15-20 | Color | Larger CYD variant more screen real estate | AliExpress/Amazon
ESP32-3248S035C (CYD 3.5 Cap) | 3.5 | 320x480 | TFT ST7796 | Capacitive | Yes (WROOM-32) | $18-25 | Color | Capacitive 3.5" CYD best value for capacitive | AliExpress/Amazon
Elecrow CrowPanel 2.4 | 2.4 | 240x320 | TFT ILI9341 | Resistive | Yes (WROOM-32) | $12-15 | Color | Similar to CYD good documentation | Elecrow
Elecrow CrowPanel 2.8 | 2.8 | 240x320 | TFT ILI9341 | Resistive | Yes (WROOM-32) | $14-18 | Color | Good build quality LVGL compatible | Elecrow
Elecrow CrowPanel 3.5 | 3.5 | 320x480 | TFT ILI9488 | Capacitive | Yes (WROOM-32) | $25-35 | Color | IPS panel better viewing angles | Elecrow
WT32-SC01 | 3.5 | 320x480 | TFT | Capacitive | Yes (WROVER-B) | $25-35 | Color | 8MB PSRAM good for graphics | Seeed/Amazon
WT32-SC01 Plus | 3.5 | 320x480 | TFT | Capacitive | Yes (ESP32-S3) | $35-45 | Color | ESP32-S3 more GPIO 16MB flash | Seeed/Amazon
Waveshare ESP32-S3-Touch-LCD-2 | 2.0 | 240x320 | TFT ST7789 | Capacitive | Yes (ESP32-S3) | $20-28 | Color | Compact with 6-axis sensor battery charging | Waveshare
Waveshare ESP32-S3-Touch-LCD-1.28 | 1.28 | 240x240 | IPS GC9A01 | Capacitive | Yes (ESP32-S3) | $18-25 | Color | Round display smartwatch style | Waveshare
Waveshare ESP32-S3-Touch-LCD-1.85C | 1.85 | 360x360 | IPS Round | Capacitive | Yes (ESP32-S3) | $33-48 | Color | Round display built-in mic box version available | Waveshare
Waveshare ESP32-S3-Touch-LCD-3.5 | 3.5 | 320x480 | IPS | Capacitive | Yes (ESP32-S3) | $35-45 | Color | High quality IPS 262K colors camera interface | Waveshare
M5Stack Dial | 1.28 | 240x240 | TFT Round | Capacitive | Yes (ESP32-S3) | $35-40 | Color | Rotary encoder RFID RTC buzzer premium build | M5Stack
Elecrow Rotary 1.28 | 1.28 | 240x240 | IPS Round | Capacitive | Yes (ESP32-S3) | $29-38 | Color | Rotary knob input ambient lighting | Elecrow
Elecrow Rotary 2.1 | 2.1 | 480x480 | IPS Round | Capacitive | Yes (ESP32-S3) | $36-44 | Color | Larger round display rotary input | Elecrow
LILYGO T-RGB 2.1 | 2.1 | 480x480 | IPS Round | Capacitive | Yes (ESP32-S3) | $40-50 | Color | High resolution round display RGB lighting | LILYGO/AliExpress
Standalone ILI9341 2.8 + Touch | 2.8 | 240x320 | TFT | Resistive | No | $8-12 | Color | Requires separate ESP32 more wiring | AliExpress
Standalone ILI9341 2.8 Cap | 2.8 | 240x320 | TFT | Capacitive (FT6336) | No | $12-18 | Color | Requires separate ESP32 FT6336 touch controller | AliExpress
SSD1306 OLED 0.96 | 0.96 | 128x64 | OLED | None | No | $3-5 | Mono (White/Blue/Yellow) | No touch very cheap crisp display | AliExpress
SSD1306 OLED 1.3 | 1.3 | 128x64 | OLED | None | No | $4-7 | Mono (White/Blue) | No touch larger OLED option | AliExpress
SH1106 OLED 1.3 | 1.3 | 128x64 | OLED | None | No | $5-8 | Mono (White/Blue) | Alternative OLED driver to SSD1306 | AliExpress
OLED 2.4 SSD1309 | 2.4 | 128x64 | OLED | None | No | $15-25 | Mono (Yellow/White) | Larger OLED no touch | Various
Custom OLED + Touch Overlay | 2.0-2.4 | 128x64 | OLED | Capacitive (custom) | No | $40-60+ | Mono | Requires custom overlay very limited availability | Raystar/Orient
Waveshare ESP32-C6-Touch-AMOLED-1.8 | 1.8 | 360x360 | AMOLED | Capacitive | Yes (ESP32-C6) | $29-44 | Color | AMOLED beautiful colors mic+speaker IMU RTC | Waveshare
Waveshare ESP32-S3-Touch-LCD-4.3 | 4.3 | 800x480 | IPS | Capacitive | Yes (ESP32-S3) | $45-60 | Color | Large display CAN RS485 I2C TF card slot | Waveshare
Elecrow CrowPanel 4.3 | 4.3 | 480x272 | TFT RGB | Capacitive | Yes | $35-45 | Color | Good for home automation dashboards | Elecrow

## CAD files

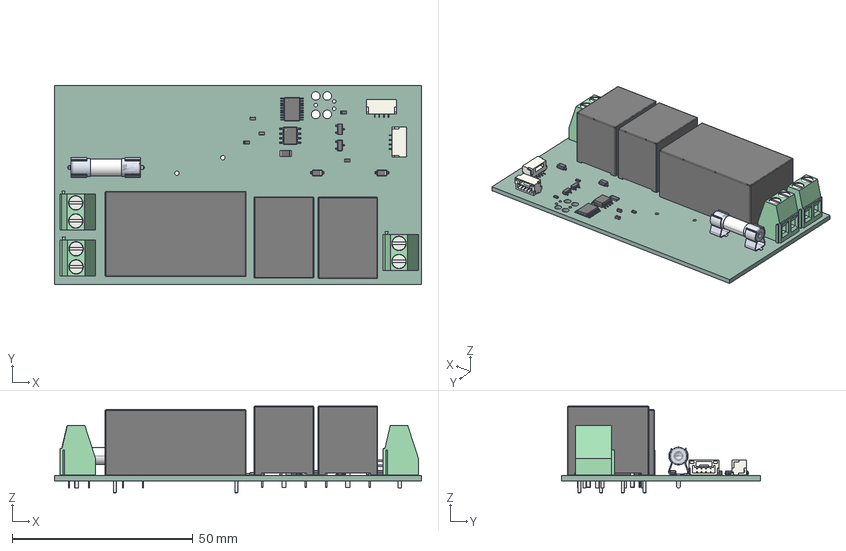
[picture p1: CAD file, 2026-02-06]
hardware/3dmodels/iot_crockpot.step
101.5 x 54.9 x 24.0 mm
TSSOP-20_4.4x6.5mm_P0.65mm
C_0603_1608Metric x 2
TerminalBlock_Phoenix_MKDS-1,5-2_1x02_P5.00mm_Horizontal x 3
R_0603_1608Metric x 3
SOIC-8_3.9x4.9mm_P1.27mm
Converter_ACDC_Hi-Link_HLK-5Mxx
SOT-23 x 2
Fuse_1206_3216Metric
D_SOD-123 x 2
Relay_SPDT_Omron-G5LE-1 x 2
Fuse Clip x 2
3A Fuse
JST_GH_SM04B-GHS-TB_1x04-1MP_P1.25mm_Horizontal x 2
iot_crockpot_PCB

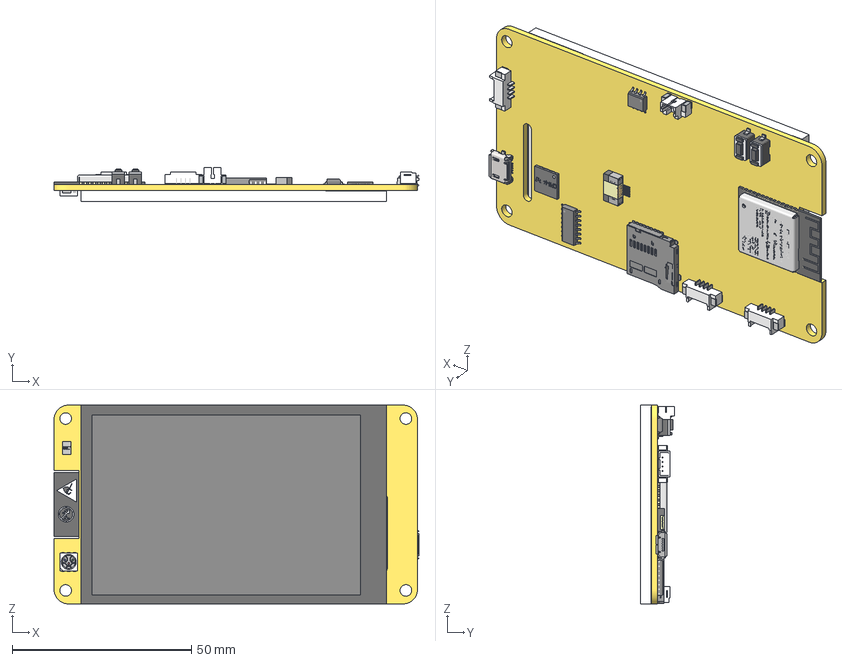
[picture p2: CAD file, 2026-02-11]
hardware/CYD PCB v8 v1.3mf
101.9 x 9.37 x 55.5 mm
CYD PCB
TFT

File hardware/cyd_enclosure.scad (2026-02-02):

// CYD 3.5" Display + Relay Enclosure for Crockpot
// Angled display with overhang, flat back
//
// SIDE VIEW:
//
//         ╱────│
//        ╱     │  <- display at 20° angle
//       ╱      │
//      ╱───────┤  <- barrier + signal slot
//     │ ░░░░░░ │  <- relay section (uniform depth)
//     │  SSR   │
//     │  PSU   │
//     └────────┘
//         ╔═╗
//         ║ ║  <- switch cylinder slides in
//     ════╩═╩════ crockpot
//

/* [Crockpot Switch Cylinder] */
switch_cylinder_od = 22;     // mm - measure this
switch_cylinder_height = 12; // mm
socket_clearance = 0.5;      // mm

/* [CYD 3.5" Display - ESP32-3248S035C actual dimensions] */
cyd_width = 101.5;           // mm - PCB width
cyd_height = 55;             // mm - PCB height
cyd_pcb_thickness = 1.6;     // mm - PCB thickness
cyd_component_height = 10;   // mm - components on back (ESP32 module, etc)
cyd_depth = cyd_pcb_thickness + cyd_component_height;  // total depth
cyd_screen_width = 73.5;     // mm - active display area
cyd_screen_height = 49;      // mm - active display area
cyd_screen_offset_x = 5;     // mm - screen offset from left edge
cyd_screen_offset_y = 3;     // mm - screen offset from bottom edge
cyd_bezel_thickness = 4;     // mm - display bezel/glass on front
// Mounting holes (estimated - 4 corners)
cyd_hole_dia = 3;            // mm - M3 mounting holes
cyd_hole_inset = 3;          // mm - distance from edge to hole center

/* [Display Angle] */
display_angle = 20;          // degrees - tilt toward user

/* [Relay Section] */
// Tall components (SSR ~20mm, HLK-PM01 ~20mm) go at BOTTOM (low Y)
max_component_height = 22;   // mm - tallest component (HLK-PM01 or SSR)
relay_depth = 20;            // mm - reduced depth for relay section

/* [Isolation] */
isolation_gap = 6;           // mm
barrier_thickness = 2;       // mm
signal_slot_width = 12;      // mm
signal_slot_height = 5;      // mm

/* [Enclosure] */
wall_thickness = 2.5;        // mm

// Derived dimensions
enclosure_width = cyd_width + wall_thickness * 2 + 2;
enclosure_height = cyd_height + wall_thickness * 2 + 2;
socket_id = switch_cylinder_od + socket_clearance * 2;

// Overhang calculated from angle so front face and display are PARALLEL
display_overhang = enclosure_height * tan(display_angle);

// Calculate geometry - display depth is part of the angled section, not added to back
back_depth = relay_depth + wall_thickness + isolation_gap + barrier_thickness;

$fn = 64;

module assembly() {
    color("DarkSlateGray") enclosure_body();

    barrier_z = cyd_depth + cyd_bezel_thickness + wall_thickness + 3;

    // CYD dummy (angled - bottom near barrier, top forward)
    %translate([wall_thickness + 1, enclosure_height - wall_thickness - 1, -display_overhang + wall_thickness])
        rotate([-display_angle, 0, 0])
            translate([0, -cyd_height, 0])
                cyd_dummy();

    // Relay components in relay section at TOP (high Y - near socket)
    %translate([wall_thickness + 5, enclosure_height - wall_thickness - 25, barrier_z + barrier_thickness + isolation_gap + 2])
        relay_components_dummy();

    // Switch cylinder dummy at TOP (high Y - slides in from crockpot)
    %translate([enclosure_width/2, enclosure_height - wall_thickness - socket_id/2 - 3, back_depth + 2])
        color("Brown", 0.3)
            cylinder(d=switch_cylinder_od, h=switch_cylinder_height);
}

module enclosure_body() {
    // front_bottom_z = 0 (reference point)
    // front_top_z = -display_overhang (overhangs forward)
    // back is at uniform depth: back_depth

    difference() {
        // Main body with angled front, flat back
        hull() {
            // Front bottom edge (at z=0)
            translate([0, 0, 0])
                cube([enclosure_width, 0.1, wall_thickness]);

            // Front top edge (overhangs forward, negative z)
            translate([0, enclosure_height, -display_overhang])
                cube([enclosure_width, 0.1, wall_thickness]);

            // Back bottom edge
            translate([0, 0, back_depth])
                cube([enclosure_width, 0.1, wall_thickness]);

            // Back top edge (same depth - flat back)
            translate([0, enclosure_height, back_depth])
                cube([enclosure_width, 0.1, wall_thickness]);
        }

        // ========== DISPLAY POCKET (angled) ==========

        // Display bottom is near barrier, top overhangs forward
        // Pocket includes space for bezel in front and components behind
        translate([wall_thickness + 1, enclosure_height - wall_thickness - 1, -display_overhang + wall_thickness])
            rotate([-display_angle, 0, 0])
                translate([0, -cyd_height, -cyd_bezel_thickness - 1])
                    cube([cyd_width, cyd_height, cyd_depth + cyd_bezel_thickness + 2]);

        // Screen cutout (angled, through front face)
        translate([
            wall_thickness + 1 + cyd_screen_offset_x,
            enclosure_height - wall_thickness - 1 - cyd_height + cyd_screen_offset_y,
            -display_overhang - 5
        ])
            rotate([-display_angle, 0, 0])
                translate([0, 0, 0])
                    cube([cyd_screen_width, cyd_screen_height, wall_thickness + display_overhang + 10]);

        // USB access (left side, near bottom of display which is now at back)
        translate([-0.1, wall_thickness + 15, wall_thickness + cyd_depth])
            cube([wall_thickness + 0.2, 14, 10]);

        // ========== RELAY CAVITY (uniform depth) ==========

        barrier_z = cyd_depth + cyd_bezel_thickness + wall_thickness + 3;  // after display section

        translate([wall_thickness, wall_thickness, barrier_z + barrier_thickness + isolation_gap])
            cube([
                enclosure_width - wall_thickness * 2,
                enclosure_height - wall_thickness * 2,
                relay_depth
            ]);

        // ========== SIGNAL SLOT ==========

        // At BOTTOM of barrier (low Y - away from mains at top)
        translate([
            wall_thickness + 8,
            wall_thickness + 8,
            barrier_z - 0.1
        ])
            cube([signal_slot_width, signal_slot_height, barrier_thickness + isolation_gap + 0.2]);

        // ========== SOCKET FOR SWITCH CYLINDER ==========

        // Open hole at back, at TOP (high Y - where mains/high power is)
        translate([enclosure_width/2, enclosure_height - wall_thickness - socket_id/2 - 3, barrier_z + barrier_thickness])
            cylinder(d=socket_id, h=back_depth);
    }

    // Isolation barrier (solid floor between display and relay)
    barrier_z = cyd_depth + cyd_bezel_thickness + wall_thickness + 3;
    difference() {
        translate([wall_thickness, wall_thickness, barrier_z])
            cube([enclosure_width - wall_thickness*2, enclosure_height - wall_thickness*2, barrier_thickness]);

        // Signal slot through barrier (at BOTTOM, low Y)
        translate([
            wall_thickness + 8,
            wall_thickness + 8,
            barrier_z - 0.1
        ])
            cube([signal_slot_width, signal_slot_height, barrier_thickness + 0.2]);
    }

    // Socket rim at TOP (high Y - where mains is)
    translate([enclosure_width/2, enclosure_height - wall_thickness - socket_id/2 - 3, back_depth - 3])
        difference() {
            cylinder(d=socket_id + 5, h=3);
            translate([0, 0, -0.1])
                cylinder(d=socket_id, h=3.2);
        }
}

module cyd_dummy() {
    // Detailed ESP32-3248S035C model

    // PCB (yellow, characteristic of CYD)
    color("Gold", 0.8)
        difference() {
            cube([cyd_width, cyd_height, cyd_pcb_thickness]);
            // Mounting holes
            for (x = [cyd_hole_inset, cyd_width - cyd_hole_inset]) {
                for (y = [cyd_hole_inset, cyd_height - cyd_hole_inset]) {
                    translate([x, y, -0.1])
                        cylinder(d=cyd_hole_dia, h=cyd_pcb_thickness + 0.2, $fn=16);
                }
            }
        }

    // Display bezel/glass (front, raised)
    color("DimGray", 0.9)
        translate([2, 1, -cyd_bezel_thickness])
            cube([cyd_width - 4, cyd_height - 2, cyd_bezel_thickness]);

    // Active display area (black screen)
    color("Black", 0.95)
        translate([cyd_screen_offset_x, cyd_screen_offset_y, -cyd_bezel_thickness - 0.1])
            cube([cyd_screen_width, cyd_screen_height, 0.2]);

    // Components on back of PCB
    // ESP32-WROOM module
    color("DarkGray", 0.7)
        translate([cyd_width - 30, 10, cyd_pcb_thickness])
            cube([25, 18, 3]);

    // SD card slot
    color("Silver", 0.8)
        translate([5, cyd_height - 15, cyd_pcb_thickness])
            cube([15, 14, 2]);

    // USB Micro connector (left side)
    color("Silver", 0.8)
        translate([-2, 20, cyd_pcb_thickness])
            cube([7, 8, 3]);
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

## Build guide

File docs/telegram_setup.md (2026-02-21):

# Telegram Bot Setup Guide

This guide explains how to create a Telegram bot and configure it for the IoT Crockpot.

## Step 1: Create a Bot with BotFather

1. Open Telegram and search for `@BotFather`
2. Start a chat and send `/newbot`
3. Follow the prompts:
   - Enter a name for your bot (e.g., "My Crockpot")
   - Enter a username (must end in `bot`, e.g., `my_crockpot_bot`)
4. BotFather will give you a **token** — save this securely

Example token format:
```
123456789:ABCdefGHIjklMNOpqrSTUvwxYZ
```

## Step 2: Find Your Chat ID

You need your Telegram chat ID to whitelist yourself and receive safety alerts.

1. Start a chat with your bot and send any message (e.g., `/start`)
2. Visit this URL in a browser, replacing `TOKEN`:
   ```
   https://api.telegram.org/botTOKEN/getUpdates
   ```
3. Find `"chat":{"id":YOUR_CHAT_ID}` in the JSON response

Alternatively, message `@userinfobot` on Telegram — it replies with your chat ID.

## Step 3: Configure the Firmware

Run `idf.py menuconfig` from the `firmware/` directory and navigate to:
**IoT Crockpot → Telegram**

| Setting | Description |
|---|---|
| **Default Telegram bot token** | Paste your token here |
| **Allowed Telegram chat ID** | Your chat ID (leave blank to allow any) |

Build and flash. The token and chat ID are saved to NVS on first use and persist across reboots and re-flashes (unless NVS is erased).

### Updating Credentials at Runtime

Token and chat ID can be updated without re-flashing by calling `telegram_set_token()` from firmware code. NVS values take priority over Kconfig defaults.

## Step 4: Test the Bot

Once the crockpot is running and connected to WiFi:

1. Send `/status` to your bot — you should receive the current state and temperature
2. Try `/help` to see all available commands

## Available Commands

| Command | Description |
|---|---|
| `/start` | Welcome message and current status |
| `/status` | Temperature, state, uptime, WiFi status |
| `/off` | Turn crockpot off |
| `/warm` | Set to warm mode |
| `/low` | Set to low mode |
| `/high` | Set to high mode |
| `/help` | List all commands |

## Automatic Safety Alerts

The bot sends an automatic alert (no command required) when a safety shutoff occurs:

- **Temperature limit exceeded**: fires when the crockpot auto-shuts off above 300°F
- **Persistent sensor error**: fires after 10 consecutive bad thermocouple readings while heating

Example alert message:
```
SAFETY SHUTOFF: Temperature 305.2 F exceeded limit. Crockpot turned OFF.
```

Alerts are sent to the **Allowed chat ID** configured in menuconfig. If no chat ID is set, alerts are silently dropped.

## Security

### Token Security
- Never share your bot token or commit it to version control
- If compromised, regenerate via BotFather: `/revoke`

### Chat ID Whitelist
Setting **Allowed Telegram chat ID** restricts the bot to only process commands from that specific user. Messages from any other chat ID are logged and ignored. Leave blank only on a private/trusted network.

## Troubleshooting

### Bot Not Responding

1. Check WiFi — serial monitor will show connection status at boot
2. Verify the token is correct (`idf.py menuconfig` or check NVS)
3. Check serial output for HTTP errors
4. Ensure `api.telegram.org` is reachable from your network

### First Response Is Slow

Long polling timeout is 30 seconds. The first message after a boot or reconnect may take up to 30s to receive a reply.

### "Unauthorized" Errors in Serial Log

Token is invalid or revoked. Regenerate with BotFather and re-configure via menuconfig.

## Example Conversation

```
You:  /status

Bot:  Crockpot Status:
      State: LOW
      Temperature: 185.4 F
      Uptime: 3600 seconds
      WiFi: Connected
      Sensor: OK

You:  /high

Bot:  Crockpot set to HIGH

--- later, safety event ---

Bot:  SAFETY SHUTOFF: Temperature 305.2 F exceeded limit. Crockpot turned OFF.
```

## BotFather Command Menu (Optional)

Set up an autocomplete menu in Telegram:

1. Message `@BotFather`, send `/setcommands`
2. Select your bot
3. Paste:

```
status - Show current status
off - Turn off
warm - Set to warm
low - Set to low
high - Set to high
help - Show help
```

Users will see this menu when they type `/` in the chat.

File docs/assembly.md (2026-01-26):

# PCB Assembly Instructions

This guide covers assembling the IoT Crockpot controller PCB.

## Before You Start

### Required Tools
- Soldering iron (temperature controlled, ~350°C / 660°F)
- Solder (lead-free recommended, 0.5-0.8mm diameter)
- Flux (no-clean recommended)
- Tweezers (fine tip)
- Multimeter
- Magnifying glass or microscope
- ESD protection (wrist strap, mat)

### Optional but Helpful
- Hot air rework station
- Solder paste and stencil (for SMD components)
- Pick and place tweezers
- Helping hands / PCB holder
- Isopropyl alcohol for cleaning

## Component Checklist

*Note: Component values TBD based on final schematic*

### SMD Components
- [ ] ESP32-WROOM-32 module
- [ ] Decoupling capacitors (100nF, 10µF)
- [ ] USB-C connector
- [ ] Voltage regulator (AMS1117-3.3 or similar)
- [ ] Status LEDs
- [ ] Resistors (various values)

### Through-Hole Components
- [ ] Relay or SSR
- [ ] Terminal blocks (for mains wiring)
- [ ] Barrel jack (optional, for external power)
- [ ] Pin headers (for programming/expansion)
- [ ] Temperature sensor connector

### Connectors
- [ ] OLED display header (4-pin I2C)
- [ ] Temperature sensor connector
- [ ] Button connectors (if separate PCB)

## Assembly Order

Follow this order for easiest assembly:

### 1. SMD Components (if applicable)

If using solder paste and reflow:
1. Apply solder paste with stencil
2. Place SMD components
3. Reflow in oven or with hot air

If hand soldering:
1. Start with smallest components
2. Work up to larger packages
3. Save ESP32 module for last

### 2. Voltage Regulator and Power Section

1. Solder the 3.3V regulator
2. Add input/output capacitors
3. Test: Apply 5V, verify 3.3V output

### 3. ESP32 Module

1. Align module carefully
2. Tack opposite corners first
3. Solder remaining pads
4. Check for bridges under module

### 4. USB Connector

1. Align connector
2. Solder mounting tabs first
3. Then solder signal pins
4. Test USB connection

### 5. Through-Hole Components

1. Install resistors and small components
2. Add terminal blocks
3. Install any remaining headers

### 6. Relay/SSR

1. Install relay module
2. Verify orientation
3. Double-check high-voltage connections

## Testing Procedure

### Visual Inspection
1. Check for solder bridges
2. Verify component orientation
3. Look for cold joints

### Power Test
1. **Do NOT connect mains power yet**
2. Connect USB power
3. Measure 3.3V rail
4. Check for excessive heat

### Programming Test
1. Connect USB to computer
2. Verify COM port appears
3. Flash test firmware
4. Check serial output

### Functional Test
1. Load full firmware
2. Verify WiFi connection
3. Test temperature sensor
4. Test relay switching (low voltage only first)
5. Test Telegram commands

### High Voltage Test (CAUTION!)
1. Triple-check all connections
2. Use isolation transformer if available
3. Test with low-power load first (e.g., lamp)
4. Verify relay switches load correctly

## Safety Checklist

Before connecting to mains:

- [ ] All low-voltage testing complete
- [ ] Enclosure properly grounded (if metal)
- [ ] Creepage distances verified
- [ ] No exposed high-voltage traces
- [ ] Strain relief on power cord
- [ ] Fuse installed and correct rating
- [ ] GFCI outlet used for testing

## Enclosure Assembly

1. Verify PCB fits in enclosure
2. Mark and drill holes for:
   - Power cord entry
   - USB port access
   - Display window (if applicable)
   - Ventilation
3. Install cable glands
4. Mount PCB with standoffs
5. Connect all wires
6. Secure lid

## Troubleshooting

### ESP32 Won't Program
- Check USB cable (data cable, not charge-only)
- Verify COM port drivers installed
- Hold BOOT button while programming
- Check for solder bridges on USB connector

### No 3.3V Output
- Check input voltage (5V)
- Verify regulator orientation
- Check for shorts on 3.3V rail

### Temperature Sensor Not Working
- Verify pull-up resistor installed
- Check sensor wiring
- Test sensor independently

### Relay Not Switching
- Check GPIO output with multimeter
- Verify relay coil voltage matches supply
- Check flyback diode orientation (if discrete)

## Version Notes

*Add notes here when PCB revisions are made*

### Rev 0.1
- Initial prototype
- Known issues: TBD

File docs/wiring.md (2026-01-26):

# Development Wiring Guide

This document describes how to wire components for development/testing before the custom PCB is ready.

## ESP32 Development Board Pinout

Using a standard ESP32 DevKit V1 or similar.

### Temperature Sensor (GPIO 4)

**DS18B20 (Recommended for development)**

```
DS18B20          ESP32
─────────        ─────
VDD (Red)   ──── 3.3V
GND (Black) ──── GND
DQ (Yellow) ──── GPIO 4
                  │
                  ├── 4.7kΩ ── 3.3V (pull-up resistor)
```

**NTC Thermistor (Alternative)**

```
                 3.3V
                  │
                  ├── 10kΩ (reference resistor)
                  │
ESP32 GPIO 36 ───┤ (ADC input)
                  │
                  ├── NTC Thermistor (10kΩ @ 25°C)
                  │
                 GND
```

### Relay Module (GPIO 5)

**Using a relay module with opto-isolation:**

```
Relay Module     ESP32
────────────     ─────
VCC         ──── 5V (or 3.3V depending on module)
GND         ──── GND
IN          ──── GPIO 5
```

**IMPORTANT SAFETY NOTES:**
- Never work on mains wiring while plugged in
- Use a relay rated for your mains voltage (120V/240V AC)
- Keep high voltage and low voltage sections separated
- Consider using a commercial smart plug for initial testing

### OLED Display (Optional)

**SSD1306 128x64 I2C OLED:**

```
OLED Display     ESP32
────────────     ─────
VCC         ──── 3.3V
GND         ──── GND
SDA         ──── GPIO 21
SCL         ──── GPIO 22
```

### Control Buttons (Optional)

```
Button           ESP32
──────           ─────
UP Button   ──── GPIO 12 ──┬── GND (internal pull-up enabled)
DOWN Button ──── GPIO 13 ──┤
SELECT      ──── GPIO 14 ──┘
```

## Complete Wiring Diagram

```
                    ┌─────────────────────────────────┐
                    │         ESP32 DevKit            │
                    │                                 │
        3.3V ◄──────┤ 3V3                       GND ├──────► GND
                    │                                 │
   DS18B20 DQ ◄─────┤ GPIO 4              GPIO 5 ├─────► Relay IN
                    │                                 │
    OLED SDA ◄──────┤ GPIO 21            GPIO 12 ├─────► Button UP
    OLED SCL ◄──────┤ GPIO 22            GPIO 13 ├─────► Button DOWN
                    │                     GPIO 14 ├─────► Button SELECT
                    │                                 │
                    │ USB (Programming & Power)       │
                    └─────────────────────────────────┘
```

## Power Supply Options

### Development (USB Power)
- Power ESP32 via USB
- Use 5V relay module powered from VIN pin
- Suitable for testing

### Standalone Operation
- 5V 2A power supply recommended
- Use voltage regulator for 3.3V components
- Consider battery backup for WiFi/settings retention

## Testing Checklist

1. [ ] ESP32 powers on and connects to WiFi
2. [ ] Temperature sensor reads reasonable values
3. [ ] Relay clicks when state changes (test with multimeter)
4. [ ] OLED displays status (if connected)
5. [ ] Buttons change state (if connected)

## Safety Reminders

- **NEVER** work on mains wiring while energized
- Use proper wire gauges for mains current
- Ensure relay is rated for your load
- Keep a fire extinguisher nearby during testing
- Consider using a GFCI outlet for testing

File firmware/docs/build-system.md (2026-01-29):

# ESP-IDF Build System

This document explains how the firmware is built using ESP-IDF.

## Overview

ESP-IDF uses a Python-based build system that wraps CMake and Ninja. The main entry point is `idf.py`, which orchestrates compilation, flashing, and monitoring.

## Build Flow

```
idf.py build
    │
    ├─→ CMake         Configure project, generate build files
    │
    ├─→ Ninja         Compile C/C++ code using GCC toolchain
    │
    └─→ Output        Binary files in build/ directory
```

## Key Python Scripts

| Script | Location | Purpose |
|---|---|---|
| `idf.py` | `$IDF_PATH/tools/idf.py` | Main CLI wrapper |
| `esptool.py` | `$IDF_PATH/components/esptool_py/esptool/` | Flash firmware to ESP32 |
| `idf_monitor.py` | `$IDF_PATH/tools/idf_monitor.py` | Serial monitor with crash decoding |

### idf.py

The main command-line interface. Routes commands to appropriate tools:

```bash
idf.py set-target esp32c3   # Configure for ESP32-C3
idf.py menuconfig           # Interactive configuration
idf.py build                # Compile firmware
idf.py flash                # Write to device
idf.py monitor              # Serial output
idf.py clean                # Remove build artifacts
idf.py fullclean            # Remove all generated files
```

### esptool.py

Handles communication with the ESP32 bootloader:
- Writes firmware binary to flash
- Can read/write flash contents
- Verifies flash after write

Called automatically by `idf.py flash`.

### idf_monitor.py

Enhanced serial monitor:
- Displays serial output from device
- Decodes crash stack traces to source file:line
- Supports GDB integration
- Keyboard shortcuts (Ctrl+] to exit)

## Build Configuration

### sdkconfig.defaults

Default options applied when configuring a new build:

```
CONFIG_IDF_TARGET="esp32c3"     # Target chip
CONFIG_ESP_WIFI_SSID=""          # WiFi credentials
CONFIG_FREERTOS_HZ=1000          # Tick rate
```

### sdkconfig

Full configuration file generated by CMake. Contains all options (defaults + menuconfig changes). This file is regenerated when you run `idf.py menuconfig`.

**Note**: Delete `sdkconfig` when changing target chips to force regeneration.

### CMakeLists.txt (main/)

Registers the main component with its source files and dependencies:

```cmake
idf_component_register(
    SRCS "main.c" "wifi.c" "temperature.c" ...
    INCLUDE_DIRS "."
    REQUIRES nvs_flash esp_wifi driver ...
)
```

## Toolchain

ESP-IDF installs the appropriate GCC toolchain:

| Target | Toolchain |
|---|---|
| ESP32 | xtensa-esp32-elf-gcc |
| ESP32-S2 | xtensa-esp32s2-elf-gcc |
| ESP32-S3 | xtensa-esp32s3-elf-gcc |
| ESP32-C3 | riscv32-esp-elf-gcc |

The ESP32-C3 uses a RISC-V core, so it needs the RISC-V toolchain.

## Build Output

After `idf.py build`, the `build/` directory contains:

```
build/
├── bootloader/           # Second-stage bootloader
├── partition_table/      # Flash partition info
├── iot_crockpot.bin      # Main application binary
├── iot_crockpot.elf      # ELF with debug symbols
└── flash_args            # Arguments for esptool
```

## Common Issues

### "No such command" or "idf.py not found"

ESP-IDF environment not set up. Run:
- Windows: Open "ESP-IDF Command Prompt" from Start menu
- Linux/Mac: `source $IDF_PATH/export.sh`

### Build fails after changing target

Delete `sdkconfig` and rebuild:

```bash
rm sdkconfig
idf.py set-target esp32c3
idf.py build
```

### Flash fails with "Permission denied"

- Windows: Install USB drivers (CP210x or CH340 depending on board)
- Linux: Add user to dialout group: `sudo usermod -a -G dialout $USER`

## References

- [ESP-IDF Programming Guide](https://docs.espressif.com/projects/esp-idf/en/latest/esp32c3/)
- [ESP-IDF Build System](https://docs.espressif.com/projects/esp-idf/en/latest/esp32c3/api-guides/build-system.html)
- [esptool.py Documentation](https://docs.espressif.com/projects/esptool/en/latest/)

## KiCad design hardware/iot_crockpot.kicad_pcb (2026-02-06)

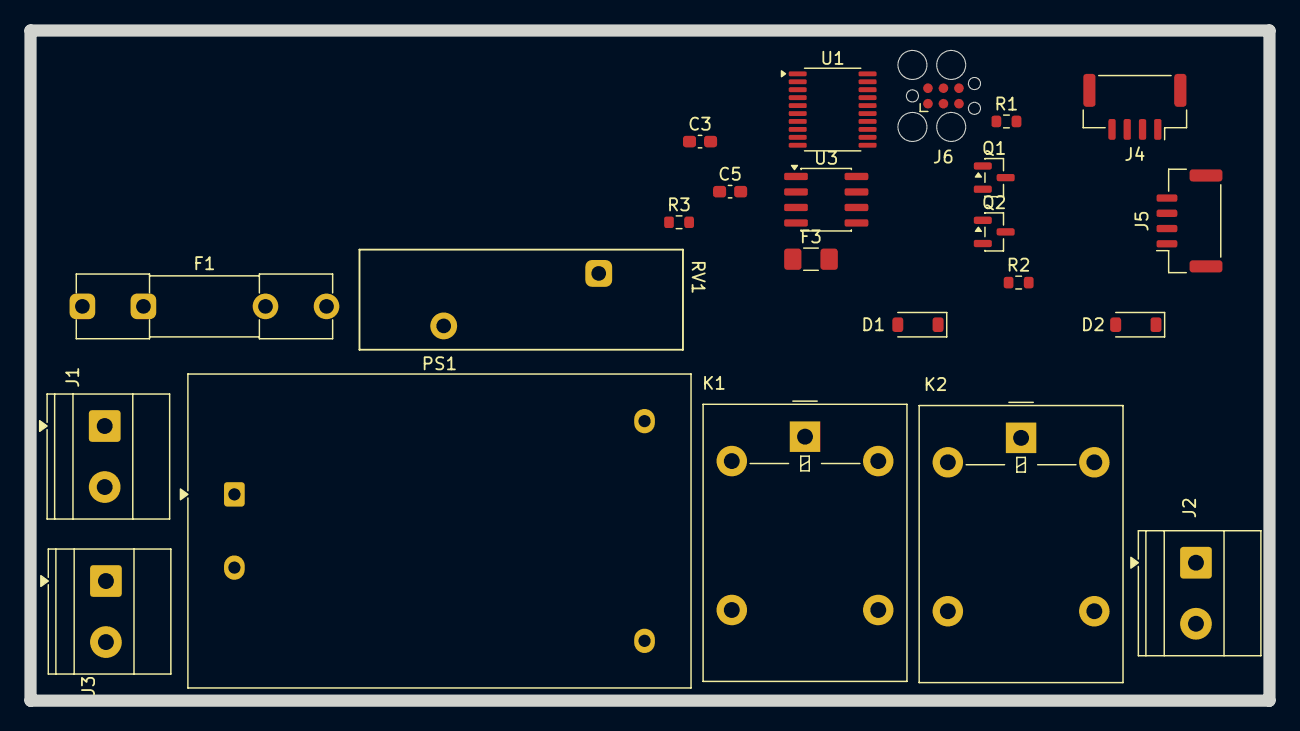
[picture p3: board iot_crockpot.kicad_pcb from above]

Board: 2 copper layers, 101.5 x 54.9 mm, 23 parts (0 on the bottom side), 19 nets, no tracks yet.

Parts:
C3, C5: 0.1uF; C_0603_1608Metric_Pad1.08x0.95mm_HandSolder
D1, D2: 1N4148W; D_SOD-123
F1: Fuse; Fuseholder_Clip-5x20mm_Littelfuse_111_Inline_P20.00x5.00mm_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
F3: 1.5A; Fuse_1206_3216Metric_Pad1.42x1.75mm_HandSolder
J1, J2, J3: Screw_Terminal_01x02; TerminalBlock_Phoenix_MKDS-1,5-2_1x02_P5.00mm_Horizontal
J4, J5: Conn_01x04_Pin; JST_GH_SM04B-GHS-TB_1x04-1MP_P1.25mm_Horizontal
J6: Conn_ARM_SWD_TagConnect_TC2030; Tag-Connect_TC2030-IDC-FP_2x03_P1.27mm_Vertical
K1, K2: G5LE-14 5VDC; Relay_SPDT_Omron-G5LE-1
PS1: HLK-5M05; Converter_ACDC_Hi-Link_HLK-5Mxx
Q1, Q2: 2N7002; SOT-23
R1, R2, R3: 10k; R_0603_1608Metric
RV1: Varistor; RV_Rect_V25S440P_L26.5mm_W8.2mm_P12.7mm
U1: STM32G031F6Px; TSSOP-20_4.4x6.5mm_P0.65mm
U3: MAX31855KASA; SOIC-8_3.9x4.9mm_P1.27mm

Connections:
+3V3: C3.1, C5.1, J6.1 (VCC), R3.1, U1.4 (VDD), U3.4 (V_{CC})
+5V: D1.1 (K), D2.1 (K), F3.2, K1.5, K2.5
/HOT: F1.1, J1.2
/MAX31855_CS_N: R3.2, U1.12 (PA5), U3.6 (~CS)
/NEUTRAL: J1.1, RV1.2
/RELAY_1: Q2.1 (G), R2.1, U1.14 (PA7)
/RELAY_2: Q1.1 (G), R1.1, U1.15 (PA8/PB0/PB1/PB2)
/RELAY_HOT: K1.1, K2.1
/SPI1_MISO: U1.13 (PA6), U3.7 (SO)
/SPI1_SCK: U1.8 (PA1), U3.5 (SCK)
GND: C3.2, C5.2, J6.5 (GND), PS1.3 (-Vout), Q1.2 (S), Q2.2 (S), R1.2, R2.2, U1.5 (VSS), U3.1 (GND)
unnamed: F1.2, RV1.1
unnamed: D1.2 (A), K1.2, Q2.3 (D)
unnamed: D2.2 (A), K2.2, Q1.3 (D)
unnamed: J2.1, K1.4
unnamed: J2.2, K2.4
unnamed: J3.1, U3.2 (T-)
unnamed: J3.2, U3.3 (T+)
unnamed: F3.1, PS1.4 (+Vout)

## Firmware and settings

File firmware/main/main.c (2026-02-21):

/**
 * @file main.c
 * @brief IoT Crockpot main entry point
 *
 * Initializes all subsystems and starts FreeRTOS tasks.
 */

#include <stdio.h>
#include "freertos/FreeRTOS.h"
#include "freertos/task.h"
#include "esp_log.h"
#include "esp_system.h"
#include "esp_chip_info.h"
#include "esp_idf_version.h"
#include "esp_task_wdt.h"

#include "wifi.h"
#include "crockpot.h"
#include "telegram.h"
#include "display.h"
#include "gui.h"

static const char* TAG = "main";

// Task stack sizes
#define CONTROL_TASK_STACK_SIZE   4096
#define TELEGRAM_TASK_STACK_SIZE  8192
#define DISPLAY_TASK_STACK_SIZE   4096

// Task priorities (higher number = higher priority)
#define CONTROL_TASK_PRIORITY     5
#define TELEGRAM_TASK_PRIORITY    3
#define DISPLAY_TASK_PRIORITY     4

// Alert callback — fired by crockpot_control_task on safety shutoff
static void on_safety_alert(crockpot_alert_t reason, float temp_f)
{
    char msg[128];
    if (reason == CROCKPOT_ALERT_TEMP_LIMIT) {
        snprintf(msg, sizeof(msg),
                 "SAFETY SHUTOFF: Temperature %.1f F exceeded limit. Crockpot turned OFF.", temp_f);
    } else {
        snprintf(msg, sizeof(msg),
                 "SAFETY SHUTOFF: Persistent sensor error. Crockpot turned OFF.");
    }
    ESP_LOGW(TAG, "%s", msg);
    telegram_queue_alert(msg);
    gui_show_error(msg);
}

void app_main(void)
{
    // --- Boot log ---
    esp_chip_info_t chip;
    esp_chip_info(&chip);
    ESP_LOGI(TAG, "=================================");
    ESP_LOGI(TAG, "    IoT Crockpot Controller");
    ESP_LOGI(TAG, "=================================");
    ESP_LOGI(TAG, "Firmware:  0.1.0");
    ESP_LOGI(TAG, "IDF:       %s", esp_get_idf_version());
    ESP_LOGI(TAG, "Chip:      %s  cores=%d  rev=%d",
             CONFIG_IDF_TARGET, chip.cores, chip.revision);
    ESP_LOGI(TAG, "Flash:     %d MB  %s",
             (chip.features & CHIP_FEATURE_EMB_FLASH) ? 4 : 0,
             (chip.features & CHIP_FEATURE_WIFI_BGN) ? "WiFi" : "");
    ESP_LOGI(TAG, "SPI:       SCK=%d MOSI=%d MISO=%d",
             CONFIG_CROCKPOT_SPI_SCK, CONFIG_CROCKPOT_SPI_MOSI, CONFIG_CROCKPOT_SPI_MISO);
    ESP_LOGI(TAG, "Display:   CS=%d DC=%d RST=%d BL=%d",
             CONFIG_CROCKPOT_LCD_CS, CONFIG_CROCKPOT_LCD_DC,
             CONFIG_CROCKPOT_LCD_RST, CONFIG_CROCKPOT_LCD_BL);
    ESP_LOGI(TAG, "Touch:     SDA=%d SCL=%d RST=%d INT=%d",
             CONFIG_CROCKPOT_TOUCH_SDA, CONFIG_CROCKPOT_TOUCH_SCL,
             CONFIG_CROCKPOT_TOUCH_RST, CONFIG_CROCKPOT_TOUCH_INT);
    ESP_LOGI(TAG, "TC CS:     GPIO %d", CONFIG_CROCKPOT_TC_CS);
    ESP_LOGI(TAG, "Relay:     GPIO %d  active-%s",
             CONFIG_CROCKPOT_RELAY_GPIO,
             CONFIG_CROCKPOT_RELAY_ACTIVE_HIGH ? "high" : "low");
    ESP_LOGI(TAG, "Starting initialization...");

    // Initialize WiFi
    ESP_LOGI(TAG, "Initializing WiFi...");
    if (!wifi_init()) {
        ESP_LOGE(TAG, "WiFi initialization failed!");
        // Continue without WiFi - local control still works
    } else {
        // Start WiFi connection
        if (!wifi_connect()) {
            ESP_LOGE(TAG, "Failed to start WiFi connection");
        }
    }

    // Initialize crockpot core
    ESP_LOGI(TAG, "Initializing crockpot core...");
    if (!crockpot_init()) {
        ESP_LOGE(TAG, "Crockpot initialization failed!");
        esp_restart();
    }
    crockpot_set_alert_callback(on_safety_alert);

    // Initialize display hardware + LVGL
    ESP_LOGI(TAG, "Initializing display...");
    if (!display_init()) {
        ESP_LOGW(TAG, "Display initialization failed - continuing without local UI");
    } else {
        // Build LVGL screen objects and start the status update timer
        if (!gui_init()) {
            ESP_LOGW(TAG, "GUI init failed");
        } else {
            gui_start();
        }
    }

    // Initialize Telegram interface
    ESP_LOGI(TAG, "Initializing Telegram interface...");
    if (!telegram_init()) {
        ESP_LOGW(TAG, "Telegram initialization failed - continuing without remote control");
    }

    // Wait for WiFi connection (with timeout)
    ESP_LOGI(TAG, "Waiting for WiFi connection...");
    if (wifi_wait_connected(WIFI_CONNECT_TIMEOUT_MS)) {
        char ip_str[16];
        if (wifi_get_ip_string(ip_str, sizeof(ip_str))) {
            ESP_LOGI(TAG, "WiFi connected! IP: %s", ip_str);
        }
    } else {
        ESP_LOGW(TAG, "WiFi connection timed out - continuing in offline mode");
    }

    // Create FreeRTOS tasks
    ESP_LOGI(TAG, "Creating tasks...");

    // Control task - main state machine loop
    BaseType_t ret = xTaskCreate(
        crockpot_control_task,
        "control",
        CONTROL_TASK_STACK_SIZE,
        NULL,
        CONTROL_TASK_PRIORITY,
        NULL
    );
    if (ret != pdPASS) {
        ESP_LOGE(TAG, "Failed to create control task");
        esp_restart();
    }

    // Telegram task - remote control via Telegram bot
    ret = xTaskCreate(
        telegram_task,
        "telegram",
        TELEGRAM_TASK_STACK_SIZE,
        NULL,
        TELEGRAM_TASK_PRIORITY,
        NULL
    );
    if (ret != pdPASS) {
        ESP_LOGW(TAG, "Failed to create Telegram task");
    }

    // Display task - local UI
    ret = xTaskCreate(
        display_task,
        "display",
        DISPLAY_TASK_STACK_SIZE,
        NULL,
        DISPLAY_TASK_PRIORITY,
        NULL
    );
    if (ret != pdPASS) {
        ESP_LOGW(TAG, "Failed to create display task");
    }

    ESP_LOGI(TAG, "=================================");
    ESP_LOGI(TAG, "    Initialization complete!");
    ESP_LOGI(TAG, "=================================");

    // Main task can be deleted - all work is done in other tasks
    // Or we can use it for watchdog feeding and health monitoring
    while (1) {
        // Log periodic status
        crockpot_status_t status = crockpot_get_status();
        ESP_LOGI(TAG, "Status: %s | Temp: %.1f F | Uptime: %lu s | WiFi: %s",
                 crockpot_state_to_string(status.state),
                 status.temperature_f,
                 (unsigned long)status.uptime_seconds,
                 status.wifi_connected ? "OK" : "DISCONNECTED");

        vTaskDelay(pdMS_TO_TICKS(30000));  // Log every 30 seconds
    }
}

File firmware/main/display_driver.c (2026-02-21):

/**
 * @file display_driver.c
 * @brief ST7796 SPI display driver implementation
 *
 * Orientation notes (may need tuning per physical module):
 *   swap_xy=true + mirror_x=true gives landscape with USB-C at the bottom.
 *   If the image appears rotated or mirrored, adjust the swap/mirror calls
 *   in display_driver_init() and update LVGL's rotation setting to match.
 *
 * Color inversion:
 *   ST7796 modules from lcdwiki/Hosyond/Waveshare typically require
 *   invert_color=true for correct colors. Disable if colors appear inverted.
 */

#include "display_driver.h"
#include "spi_bus.h"

#include "driver/gpio.h"
#include "esp_lcd_panel_io.h"
#include "esp_lcd_panel_ops.h"
#include "esp_lcd_st7796.h"
#include "esp_heap_caps.h"
#include "esp_log.h"
#include <string.h>

static const char *TAG = "display_driver";

static esp_lcd_panel_handle_t    s_panel_handle = NULL;
static esp_lcd_panel_io_handle_t s_io_handle    = NULL;
static bool                      s_initialized  = false;

bool display_driver_init(void)
{
    if (s_initialized) {
        return true;
    }

    ESP_LOGI(TAG, "Initializing ST7796 display (CS=%d DC=%d RST=%d BL=%d)",
             CONFIG_CROCKPOT_LCD_CS, CONFIG_CROCKPOT_LCD_DC,
             CONFIG_CROCKPOT_LCD_RST, CONFIG_CROCKPOT_LCD_BL);

    // --- Backlight GPIO ---
    if (CONFIG_CROCKPOT_LCD_BL >= 0) {
        gpio_config_t bl_cfg = {
            .pin_bit_mask = (1ULL << CONFIG_CROCKPOT_LCD_BL),
            .mode         = GPIO_MODE_OUTPUT,
            .pull_up_en   = GPIO_PULLUP_DISABLE,
            .pull_down_en = GPIO_PULLDOWN_DISABLE,
            .intr_type    = GPIO_INTR_DISABLE,
        };
        gpio_config(&bl_cfg);
        gpio_set_level(CONFIG_CROCKPOT_LCD_BL, 0);  // off during init
    }

    // --- Shared SPI bus ---
    if (!spi_bus_init()) {
        ESP_LOGE(TAG, "SPI bus init failed");
        return false;
    }

    // --- esp_lcd SPI panel IO ---
    esp_lcd_panel_io_spi_config_t io_config = {
        .dc_gpio_num       = CONFIG_CROCKPOT_LCD_DC,
        .cs_gpio_num       = CONFIG_CROCKPOT_LCD_CS,
        .pclk_hz           = LCD_SPI_CLK_HZ,
        .lcd_cmd_bits      = 8,
        .lcd_param_bits    = 8,
        .spi_mode          = 0,
        .trans_queue_depth = 10,
        // on_color_trans_done and user_ctx are set by LVGL in Phase 5
        .on_color_trans_done = NULL,
        .user_ctx            = NULL,
    };

    esp_err_t ret = esp_lcd_new_panel_io_spi(
        (esp_lcd_spi_bus_handle_t)SHARED_SPI_HOST, &io_config, &s_io_handle);
    if (ret != ESP_OK) {
        ESP_LOGE(TAG, "esp_lcd_new_panel_io_spi failed: %s", esp_err_to_name(ret));
        return false;
    }

    // --- ST7796 panel ---
    esp_lcd_panel_dev_config_t panel_config = {
        .reset_gpio_num = CONFIG_CROCKPOT_LCD_RST,
        .rgb_ele_order  = LCD_RGB_ELEMENT_ORDER_BGR,
        .bits_per_pixel = 16,
    };

    ret = esp_lcd_new_panel_st7796(s_io_handle, &panel_config, &s_panel_handle);
    if (ret != ESP_OK) {
        ESP_LOGE(TAG, "esp_lcd_new_panel_st7796 failed: %s", esp_err_to_name(ret));
        return false;
    }

    // --- Panel init sequence ---
    esp_lcd_panel_reset(s_panel_handle);
    esp_lcd_panel_init(s_panel_handle);

    // ST7796 modules typically need color inversion for correct colors.
    // Disable this if your display shows inverted colors.
    esp_lcd_panel_invert_color(s_panel_handle, true);

    // Landscape orientation: 480 wide x 320 tall.
    // Adjust swap_xy / mirror_x / mirror_y if image is rotated or mirrored.
    esp_lcd_panel_swap_xy(s_panel_handle, true);
    esp_lcd_panel_mirror(s_panel_handle, true, false);

    esp_lcd_panel_set_gap(s_panel_handle, 0, 0);

    // Turn on the display
    esp_lcd_panel_disp_on_off(s_panel_handle, true);

    // Backlight on
    display_driver_set_backlight(true);

    s_initialized = true;
    ESP_LOGI(TAG, "ST7796 display initialized (%dx%d)", LCD_H_RES, LCD_V_RES);
    return true;
}

esp_lcd_panel_handle_t display_driver_get_panel(void)
{
    return s_panel_handle;
}

esp_lcd_panel_io_handle_t display_driver_get_io(void)
{
    return s_io_handle;
}

void display_driver_set_backlight(bool on)
{
    if (CONFIG_CROCKPOT_LCD_BL >= 0) {
        gpio_set_level(CONFIG_CROCKPOT_LCD_BL, on ? 1 : 0);
    }
}

void display_driver_fill(uint16_t color_rgb565)
{
    if (!s_initialized) {
        return;
    }

    // Allocate a one-line DMA-capable buffer
    uint16_t *line = heap_caps_malloc(
        LCD_H_RES * sizeof(uint16_t), MALLOC_CAP_DMA | MALLOC_CAP_INTERNAL);
    if (line == NULL) {
        ESP_LOGE(TAG, "display_driver_fill: out of memory");
        return;
    }

    for (int i = 0; i < LCD_H_RES; i++) {
        line[i] = color_rgb565;
    }

    for (int y = 0; y < LCD_V_RES; y++) {
        esp_lcd_panel_draw_bitmap(s_panel_handle, 0, y, LCD_H_RES, y + 1, line);
    }

    heap_caps_free(line);
}

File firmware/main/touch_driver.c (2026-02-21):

/**
 * @file touch_driver.c
 * @brief FT6336U capacitive touch driver implementation
 *
 * I2C address: 0x38 (fixed, FT5x06 family)
 * I2C port:    I2C_NUM_0
 * Bus speed:   400 kHz
 *
 * Orientation notes:
 *   swap_xy and mirror settings must match the display driver orientation.
 *   If touch points are misaligned with the display, adjust the flags
 *   in touch_driver_init() to match.
 */

#include "touch_driver.h"
#include "display_driver.h"   // for LCD_H_RES / LCD_V_RES

#include "driver/i2c.h"
#include "esp_lcd_panel_io.h"
#include "esp_lcd_touch_ft5x06.h"
#include "driver/gpio.h"
#include "esp_log.h"
#include <string.h>

static const char *TAG = "touch_driver";

#define TOUCH_I2C_PORT   I2C_NUM_0
#define TOUCH_I2C_FREQ   400000   // 400 kHz

static esp_lcd_touch_handle_t s_tp_handle  = NULL;
static bool                   s_initialized = false;

bool touch_driver_init(void)
{
    if (s_initialized) {
        return true;
    }

    ESP_LOGI(TAG, "Initializing FT6336U touch (SDA=%d SCL=%d RST=%d INT=%d)",
             CONFIG_CROCKPOT_TOUCH_SDA, CONFIG_CROCKPOT_TOUCH_SCL,
             CONFIG_CROCKPOT_TOUCH_RST, CONFIG_CROCKPOT_TOUCH_INT);

    // --- CTP_RST: pulse low to reset, then release ---
    if (CONFIG_CROCKPOT_TOUCH_RST >= 0) {
        gpio_config_t rst_cfg = {
            .pin_bit_mask = (1ULL << CONFIG_CROCKPOT_TOUCH_RST),
            .mode         = GPIO_MODE_OUTPUT,
            .pull_up_en   = GPIO_PULLUP_DISABLE,
            .pull_down_en = GPIO_PULLDOWN_DISABLE,
            .intr_type    = GPIO_INTR_DISABLE,
        };
        gpio_config(&rst_cfg);
        gpio_set_level(CONFIG_CROCKPOT_TOUCH_RST, 0);
        vTaskDelay(pdMS_TO_TICKS(10));
        gpio_set_level(CONFIG_CROCKPOT_TOUCH_RST, 1);
        vTaskDelay(pdMS_TO_TICKS(10));
    }

    // --- I2C bus (legacy driver API) ---
    i2c_config_t i2c_conf = {
        .mode             = I2C_MODE_MASTER,
        .sda_io_num       = CONFIG_CROCKPOT_TOUCH_SDA,
        .scl_io_num       = CONFIG_CROCKPOT_TOUCH_SCL,
        .sda_pullup_en    = GPIO_PULLUP_ENABLE,
        .scl_pullup_en    = GPIO_PULLUP_ENABLE,
        .master.clk_speed = TOUCH_I2C_FREQ,
    };

    esp_err_t ret = i2c_param_config(TOUCH_I2C_PORT, &i2c_conf);
    if (ret != ESP_OK) {
        ESP_LOGE(TAG, "i2c_param_config failed: %s", esp_err_to_name(ret));
        return false;
    }

    ret = i2c_driver_install(TOUCH_I2C_PORT, I2C_MODE_MASTER, 0, 0, 0);
    if (ret != ESP_OK) {
        ESP_LOGE(TAG, "i2c_driver_install failed: %s", esp_err_to_name(ret));
        return false;
    }

    // --- esp_lcd I2C panel IO for touch ---
    esp_lcd_panel_io_handle_t tp_io_handle = NULL;
    esp_lcd_panel_io_i2c_config_t tp_io_cfg = ESP_LCD_TOUCH_IO_I2C_FT5x06_CONFIG();

    ret = esp_lcd_new_panel_io_i2c(
        (esp_lcd_i2c_bus_handle_t)TOUCH_I2C_PORT, &tp_io_cfg, &tp_io_handle);
    if (ret != ESP_OK) {
        ESP_LOGE(TAG, "esp_lcd_new_panel_io_i2c failed: %s", esp_err_to_name(ret));
        return false;
    }

    // --- FT6336U touch handle ---
    // swap_xy and mirror must match display_driver.c orientation settings:
    //   display uses swap_xy=true, mirror_x=true → touch matches here
    esp_lcd_touch_config_t tp_cfg = {
        .x_max        = LCD_H_RES,
        .y_max        = LCD_V_RES,
        .rst_gpio_num = CONFIG_CROCKPOT_TOUCH_RST,
        .int_gpio_num = CONFIG_CROCKPOT_TOUCH_INT,
        .levels = {
            .reset     = 0,  // active-low reset
            .interrupt = 0,  // active-low interrupt
        },
        .flags = {
            .swap_xy  = 1,  // match display swap_xy=true
            .mirror_x = 1,  // match display mirror_x=true
            .mirror_y = 0,
        },
    };

    ret = esp_lcd_touch_new_i2c_ft5x06(tp_io_handle, &tp_cfg, &s_tp_handle);
    if (ret != ESP_OK) {
        ESP_LOGE(TAG, "esp_lcd_touch_new_i2c_ft5x06 failed: %s", esp_err_to_name(ret));
        return false;
    }

    s_initialized = true;
    ESP_LOGI(TAG, "FT6336U touch initialized (%dx%d)", LCD_H_RES, LCD_V_RES);
    return true;
}

esp_lcd_touch_handle_t touch_driver_get_handle(void)
{
    return s_tp_handle;
}

bool touch_driver_read(touch_point_t *point)
{
    if (!s_initialized || point == NULL) {
        if (point) {
            point->pressed = false;
            point->x = 0;
            point->y = 0;
        }
        return false;
    }

    // Trigger a read from the IC
    esp_lcd_touch_read_data(s_tp_handle);

    uint16_t x[1], y[1], strength[1];
    uint8_t  cnt = 0;
    esp_lcd_touch_get_coordinates(s_tp_handle, x, y, strength, &cnt, 1);

    point->pressed = (cnt > 0);
    point->x       = point->pressed ? x[0] : 0;
    point->y       = point->pressed ? y[0] : 0;

    return point->pressed;
}

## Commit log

2026-01-26 Add ESP-IDF firmware and KiCad hardware project structure
    Implement complete IoT crockpot controller with:
    - Core layer: state machine, temperature sensor, relay control
    - Interface layer: Telegram bot for remote control, local display UI
    - ESP-IDF build system with FreeRTOS tasks
    - KiCad project files (placeholder schematic/PCB)
    - Documentation: wiring guide, Telegram setup, assembly instructions
    [iot_crockpot.kicad_pcb, iot_crockpot.kicad_sch, partitions.csv]
2026-01-28 Started schematic part selection
    added XIAO ESP32-C3
    added HLK-PM01 120VAC to 5VDC power module
    added relays
    added thermal couple sensor
    [iot_crockpot.kicad_sch]
2026-01-28 added initial component import to pcb
    added initial component import to pcb
    [iot_crockpot.kicad_pcb]
2026-01-29 Update firmware for XIAO ESP32-C3 and MAX31855 thermocouple
    - Change build target from ESP32 to ESP32-C3 (RISC-V)
    - Implement MAX31855 SPI driver replacing temperature stub
    - Update GPIO assignments for XIAO ESP32-C3 pinout
    - Add second relay channel (aux) for future use
    - Add 10k pull-up on MAX31855 CS line in schematic
    - Fix ESP-IDF 5.x component names (esp-tls, add driver/esp_timer)
    - Add missing stdint.h includes for int64_t/uint8_t types
    - Add firmware README and build system documentation
    [iot_crockpot.kicad_sch]
2026-01-29 Update README for XIAO ESP32-C3 and current project status
    - Update hardware specs (XIAO ESP32-C3, MAX31855, G5LE-1 relays)
    - Change build target to esp32c3
    - Update development checklist (temp sensor and schematic done)
    - Fix ESP-IDF documentation link for C3
2026-01-29 Add Python TUI simulator for testing without hardware
    Simulator mirrors ESP32 firmware behavior:
    - State machine (OFF/WARM/LOW/HIGH) matching crockpot.c
    - Realistic temperature simulation with heating/cooling curves
    - Safety auto-shutoff at configurable temperature limit
    - Sensor error injection for testing safety logic
    - Hot-reload of C header constants via file watcher
    - ASCII-based TUI for Windows console compatibility
    [config_parser.py, crockpot_sim.py, main.py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]
2026-01-29 Add display options doc and GUI abstraction layer
    Display options document:
    - Resistive vs capacitive touch comparison
    - Pricing for 2.4" to 3.5" modules ($3-18 range)
    - Recommendations for budget touchscreen options
    GUI abstraction layer (hardware-independent):
    - display_hal.h/c: Drawing primitives, text, shapes
    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
2026-01-30 Add programmable schedules and temperature logging to simulator
    - Add schedule.py with ScheduleStep, Schedule, and ScheduleManager
    - Add datalog.py with LogEntry and DataLog for 60-second interval logging
    - Integrate schedule and datalog into crockpot_sim.py control loop
    - Update app.py with schedule display, progress bar, and control buttons
    - Update tui.py with schedule status and export key binding
    - Add SCHEDULE screen to gui_sim.py
    Preset schedules: Slow Cook, Quick Warm, All Day
    Data export: CSV and JSON formats to ~/.crockpot/
    [app.py, crockpot_sim.py, datalog.py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]
2026-01-30 Add cyclable menu screens with schedule builder and history
    New screens:
    - MAIN: Simplified temp display + compact state buttons (O W L H)
    - SCHEDULE_SELECT: Pick from available schedules
    - SCHEDULE_BUILDER: Create custom schedules step by step
    - HISTORY: Temperature sparkline + state timeline graph
    - SETTINGS: WiFi and display configuration
    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
2026-01-30 Fix Menu button on all screens, add Back button on Menu screen
    [app.py]
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2026-01-30 Fix schedule button height and increase container size
    [app.py]
2026-01-30 Replace Stop Schedule with Custom Schedule Builder screen
    [app.py]
2026-01-30 Fix builder screen layout - smaller time buttons
    [app.py]
2026-02-02 Add CYD enclosure design and remote control features
    Hardware:
    - Add OpenSCAD enclosure design for ESP32-3248S035C (CYD 3.5")
    - Angled display with isolation barrier for relay section
    - Socket for crockpot switch cylinder mount
    - Add display comparison spreadsheet for hardware selection
    Simulator:
    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
    [cyd_enclosure.scad, display_comparison.csv, iot_crockpot.kicad_sch]
2026-02-03 Schematic Updates - Power Supply
    Added architecture for power supply to schematic.
    Need to rethink control architecture. There is only two I/O exposed on
    CYD. May use second MCU on control board flashed and controlled over
    I2C by CYD.
    [iot_crockpot.kicad_pcb, iot_crockpot.kicad_sch]
2026-02-04 Update architecture to two-board design with CYD and STM32 power board
    - CYD (ESP32-3248S035C) handles display, WiFi, Telegram
    - STM32 on power board as I2C slave for relay and temperature
    - Power via P1 (5V), control via CN1 (I2C + 3.3V)
    - MAX31855 + K-type thermocouple for temperature sensing
2026-02-04 Added MCU to schematic
    Added MCU to schematic and organized circuits into blocks
    [iot_crockpot.kicad_sch]
2026-02-05 More Passive Part Selection
    Added passive parts/numbers and models to schematic.
    Started rough outline of PCB. Considerations will need to be done for
    angle of display in relation to height of components.
    [iot_crockpot.kicad_pcb, iot_crockpot.kicad_sch]
2026-02-06 Edited JST Connectors and created 3D model
    Edited JST Connectors and created 3D model for use in
    Fusion 360. This will drive where tall components will be placed on
    PCB.
    [iot_crockpot.kicad_pcb, iot_crockpot.kicad_sch, iot_crockpot.step]
2026-02-11 Update docs for UART architecture and protection circuits
    Migrated all documentation from I2C (2-cable) to UART (1-cable)
    design. Added AP2112K-3.3 LDO, P-FET backfeed protection, and
    UART series resistor documentation. Updated BOM, pin assignments,
    architecture diagrams, and protocol tables across all docs.
2026-02-11 Add CYD enclosure 3D model files
    Fusion 360 design and 3MF export for CYD PCB v8 enclosure.
    [CYD PCB v8 v1.3mf]
2026-02-15 Document single-board ESP32-S3 architecture decision
    Finalized architecture: ESP32-S3-WROOM-1-N4R2 single-board design
    replacing CYD + STM32 two-board approach. Added ESP32 module
    comparison, USB/JTAG debugging notes, display sourcing options,
    and ST7796 vs ILI9488 analysis.
2026-02-21 Implement LVGL GUI and complete ESP32-S3 firmware stack
    Phases 1-6 of the single-board firmware plan:
    - Kconfig.projbuild: all GPIO assignments configurable via menuconfig
    - nvs_config: NVS read/write helpers; wifi + telegram load credentials at boot
    - spi_bus: shared SPI2 bus init (display + MAX31855)
    - display_driver: ST7796 SPI panel via esp_lcd (init, backlight, fill)
    - touch_driver: FT6336U I2C touch via esp_lcd_touch_ft5x06
    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
2026-02-21 Add task watchdog, safety alert callback, and Telegram alert queue
    - crockpot: register control task with ESP task watchdog (TWDT);
    feed it each loop iteration via esp_task_wdt_reset()
    - crockpot: expose crockpot_set_alert_callback() — fires on
    heating→OFF transition (temp limit or persistent sensor error),
    called outside the state mutex so handlers can read status safely
    - telegram: add non-blocking alert queue (depth 4); drained after
    each getUpdates poll cycle via telegram_queue_alert()
    - main: register on_safety_alert() callback that queues a Telegram
    message and shows a GUI error overlay on any safety shutoff
    - main: expand boot log with chip info, IDF version, and all GPI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
    [main.c]
2026-02-21 Update docs to reflect completed single-board ESP32-S3 firmware
    - README: complete rewrite for single-board design — architecture
    diagram, correct hardware table, updated build commands (esp32s3),
    GPIO table, development status, and links to new docs
    - firmware_architecture.md: new — documents module layout, FreeRTOS
    task table, full display stack, GUI screen descriptions, control
    loop with safety system, Telegram alert queue, NVS config, TWDT,
    and sdkconfig.defaults key settings
    - firmware_plan.md: mark all 7 phases complete; add final state table
    showing implemented/deleted files
    - telegram_setup.md: update to reflect NVS token storage (done, not
    future), implemented chat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
2026-02-21 Add LVGL PC simulator for desktop UI development
    Compiles the real firmware/main/gui.c against LVGL v9 + SDL2 on the
    desktop — no hardware required. Renders a 960×640 window (2× scaled
    from the physical 480×320 display) with mouse-driven touch input.
    Layout:
    simulator/lvgl_sim/
    ├── CMakeLists.txt fetches LVGL v9.2.2 + SDL2 via FetchContent
    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
2026-02-22 Fix LVGL simulator build for Windows MSYS2 UCRT64
    - Exclude ARM Helium and NEON .S assembly (GLOB_RECURSE picked them up
    unconditionally; use TARGET_DIRECTORY set_source_files_properties)
    - Disable LVGL examples/demos build (they use disabled widgets like
    LV_USE_SLIDER and aren't needed for the simulator)
    - Add stubs for esp_lcd_panel_ops.h, esp_lcd_panel_io.h, esp_event.h
    (firmware headers transitively include these ESP-IDF headers)
    - Add Kconfig symbol defines (CONFIG_CROCKPOT_LCD_*, CONFIG_CROCKPOT_WIFI_*)
    so display_driver.h and wifi.h compile without sdkconfig.h
    - Add SDL_MAIN_HANDLED to avoid SDL renaming main→SDL_main on Windows;
    use -mconsole linker flag for console entry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
    [main.c]
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2026-02-22 Document simulator features and fix web_server URL helpers
    - Update README with schedule engine, web API, Telegram, data logging,
    thermal physics, relay mapping, and curl usage notes
    - Refactor web_server.c: extract uri_last_component/url_decode_inplace
    helpers; fix schedule/state route handlers to use them; remove dead
    url_decode function
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2026-02-22 Enable OpenSSL/TLS for Telegram; skip cert verification in simulator
    - CMakeLists.txt: switch MG_TLS from MG_TLS_NONE to MG_TLS_OPENSSL,
    link ssl and crypto (requires pacman -S mingw-w64-ucrt-x86_64-openssl)
    - telegram.c: add mg_tls_init with ca="*" in MG_EV_CONNECT to skip
    certificate verification (no system CA bundle in MSYS2 environment)
    - README: document Telegram setup steps, OpenSSL prerequisite, token
    security note, and current known issue (responses not yet working)
2026-02-23 Begin schematic rework for single-board ESP32-S3 design
    - Split KiCad schematic into hierarchical sheets (MCU + power/relay/tempsens)
    - Add docs/schematic_rework_plan.md: step-by-step guide for reworking the
    schematic from the old CYD+STM32 two-board design to the new ESP32-S3
    single-board design
    - Update all READMEs to reflect finalized single-board architecture:
    - firmware/README.md: rewrite for ESP32-S3 target, correct GPIO table
    - hardware/README.md: rewrite for single-board design, schematic status
    - README.md: update hardware checklist, add schematic_rework_plan to docs
    [MCU.kicad_sch, iot_crockpot.kicad_sch, power_relays_tempsens.kicad_sch]
